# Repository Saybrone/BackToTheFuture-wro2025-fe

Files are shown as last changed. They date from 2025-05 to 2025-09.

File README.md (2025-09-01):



# Team BACK TO THE FUTURE - WRO® 2025 Future Engineers

<table border="0">
  <tr border="0">
    <td  border="0" colspan="2">
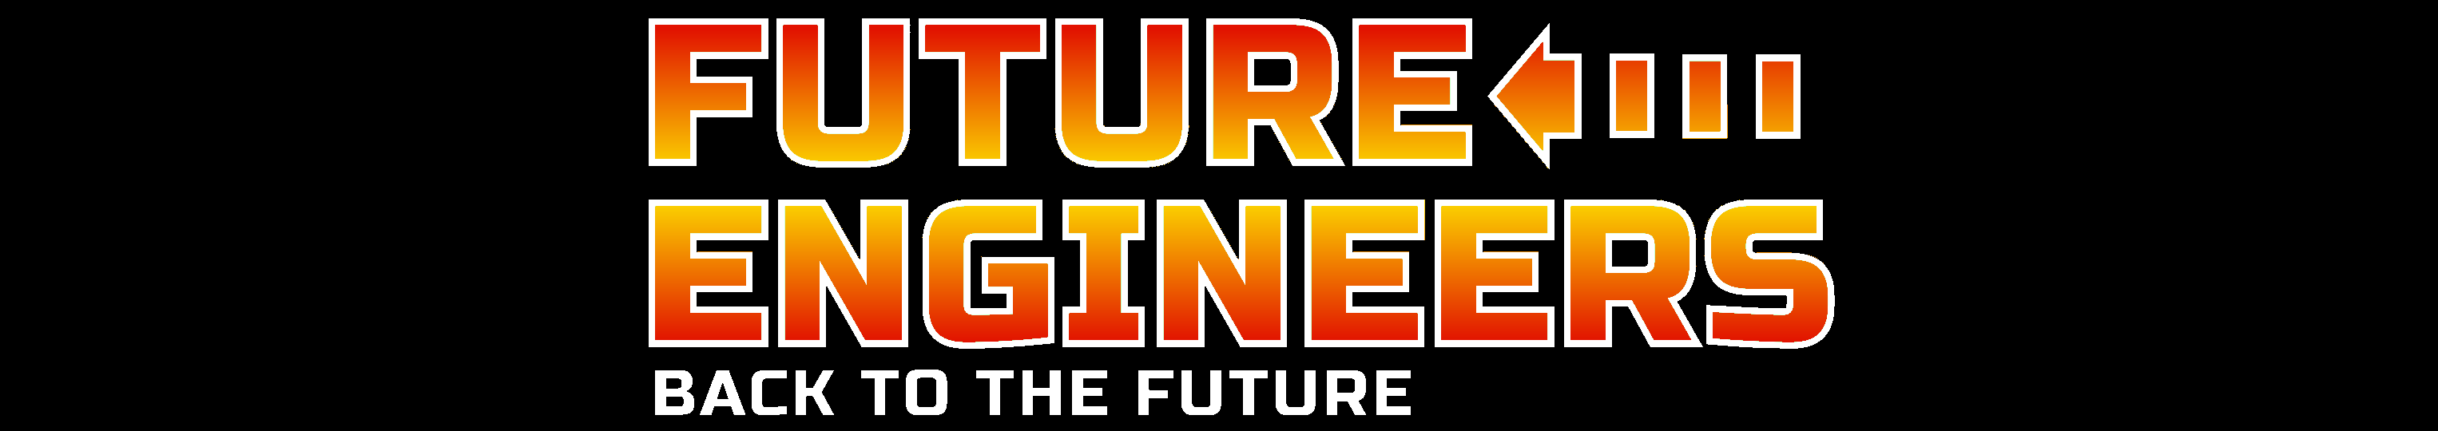
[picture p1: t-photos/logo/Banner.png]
Banner
      
    </td>
  </tr>
  <tr border="0">
    <td width="70%"  border="0">
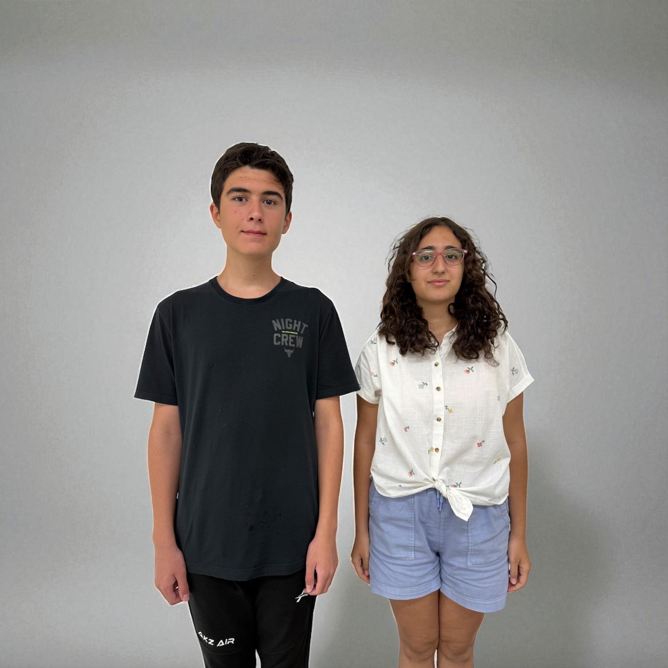
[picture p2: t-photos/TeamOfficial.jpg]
Official Photo
      
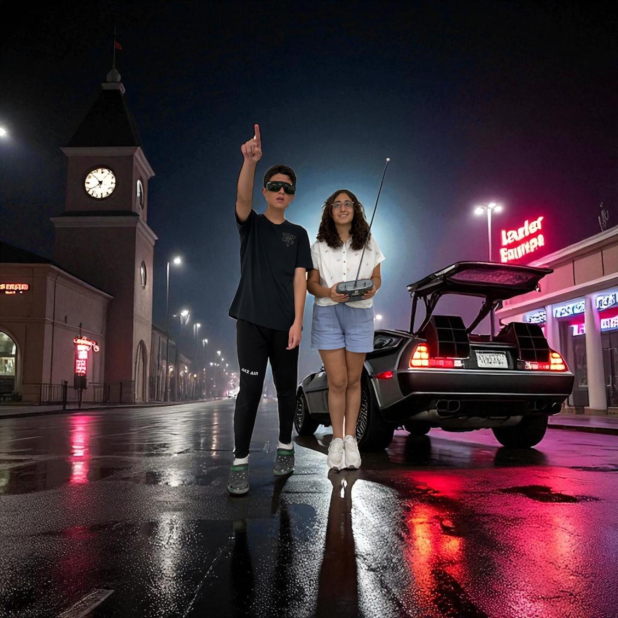
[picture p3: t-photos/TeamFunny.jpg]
Funny Photo
      
    </td>
    <td valign="top" style="padding-left: 0px;" border="0">
        This repository details team <em>Back To The Future</em>'s building and programming process in the 2025 WRO Future Engineers Competition. 
      We are team <em> Back To The Future</em>, two students who are passionate about technology and robotics. For this competition we built an autonomous vehicle. We worked after school and on weekends. Through this competition, we learned how to work as a team and solve problems related to robotics.
       </p>
        <strong>Team Members:</strong>
      <ul>
        <li>Ayça Nisa Çerçi, 16</li>
        <li>Batuhan Pekcan, 15</li>
      </ul>
      </p>
    </td>
  </tr>
</table>

  

# Table of Contents
- [Folder Contents](#folder-contents)
- [The Challenge](#the-challenge)
- [Vehicle Overview](#vehicle-overview)
  - [V-Photos](#v-photos)
  - [Hardware Components](#hardware-components)
  - [Electronic Components](#electronic-components)
  - [Mobility Management](#mobility-management)
    - [Powertrain](#powertrain)
    - [Steering](#steering)
    - [Chassis](#chassis)
- [Power and Sense Management](#power-and-sense-management)
  - [Li-ion Battery](#li-ion-battery)
  - [IMU Sensor](#imu-sensor)
  - [OpenMV Cam RT1062](#camera)
  - [EVN Alpha](#evn-alpha)
- [Software Components](#software-components)
  - [EVN Alpha Side](#evnalpha-side)
  - [OpenMV Camera Side](#openmv-side)
- [License](#license)

# Folder Contents 
* `models` is for the 3D files we used to print our parts
* `other` includes other files which can be used to understand how to prepare the vehicle for the competition. It includes documentations, datasets, hardware specifications, communication protocols,  descriptions etc.
* `schemes` contains schematic diagrams of the electromechanical components illustrating all the elements (electronic components and motors) used in the vehicle and how they connect to each other.
* `src` contains code of control software for all components which were programmed to participate in the competition
* `t-photos` contains photos of the team and logos
* `v-photos` contains 6 photos of the vehicle from various angles
* `video` contains the video.md file with the link to our YouTube channel and the respective videos

# The Challenge 

In the **[WRO 2025 Future Engineers – Self-Driving Cars](https://wro-association.org/)** category, teams are tasked with creating a robotic vehicle that can autonomously navigate a changing racetrack. Each round introduces new track layouts, requiring vehicles to adapt in real time.
The competition highlights the full engineering process:

- **Vehicle Design**: Building a functional robot with electromechanical components and advanced steering or motion systems.
- **Obstacle Management**: Applying computer vision, sensor fusion, and motion planning to make real-time decisions.
- **Project Documentation**: Maintaining an engineering journal and sharing designs in a public GitHub repository.

Teams are judged on performance, innovation, reliability, and the clarity of their engineering process, encouraging creativity, teamwork, and STEM skills.

Learn more about the challenge [here](https://wro-association.org/wp-content/uploads/WRO-2025-Future-Engineers-Self-Driving-Cars-General-Rules.pdf).

# Vehicle 
Our robot integrates LEGO components with custom 3D-printed hardware, designed to maximize stability and durability. It features a 3D-printed motor mount and camera holder, integrated with a LEGO-based chassis. For steering, we implemented a simplified Ackermann setup without linkage geometry (reckless steering), allowing the robot to turn easily while keeping the design compact. Our robot is powerized by a [GA12-N20 100RPM~6V](https://www.handsontec.com/dataspecs/GA12-N20.pdf) dc motor and controlled by an [EVNAlpha](https://evn.readthedocs.io/). It uses [OpenMV RT1062](https://openmv.io/products/openmv-cam-rt?srsltid=AfmBOorMjCmNBP1AZA_3V53JQMS-8N7Mg5ljP10ljHe4SLFoCauGWzZN) to locate obstacles, lines and walls. Steering was managed by [GeekServo 2KG Motor](https://kittenbothk-eng.readthedocs.io/en/latest/motors/2kgMotor.html). Also it uses [MPU6500 IC 6 DoF IMU Sensor](https://datasheet.octopart.com/MPU-6500-InvenSense-datasheet-138896167.pdf) to manage certain turns and hold position during movement.

## V-Photos <b class="anchor" id="v-photos"></a>
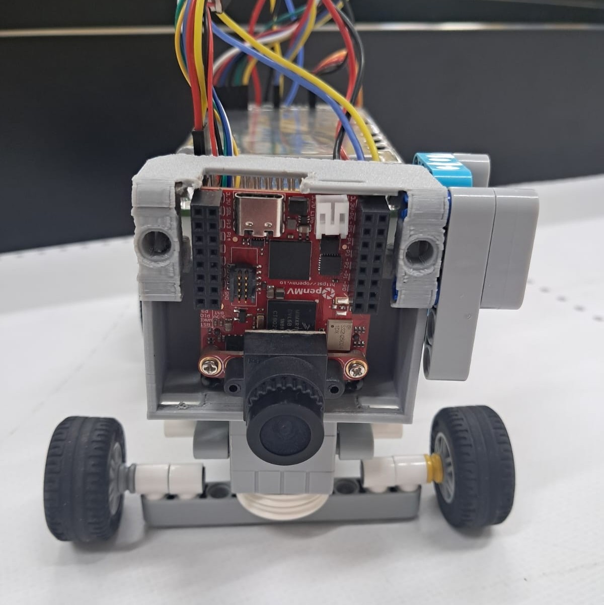
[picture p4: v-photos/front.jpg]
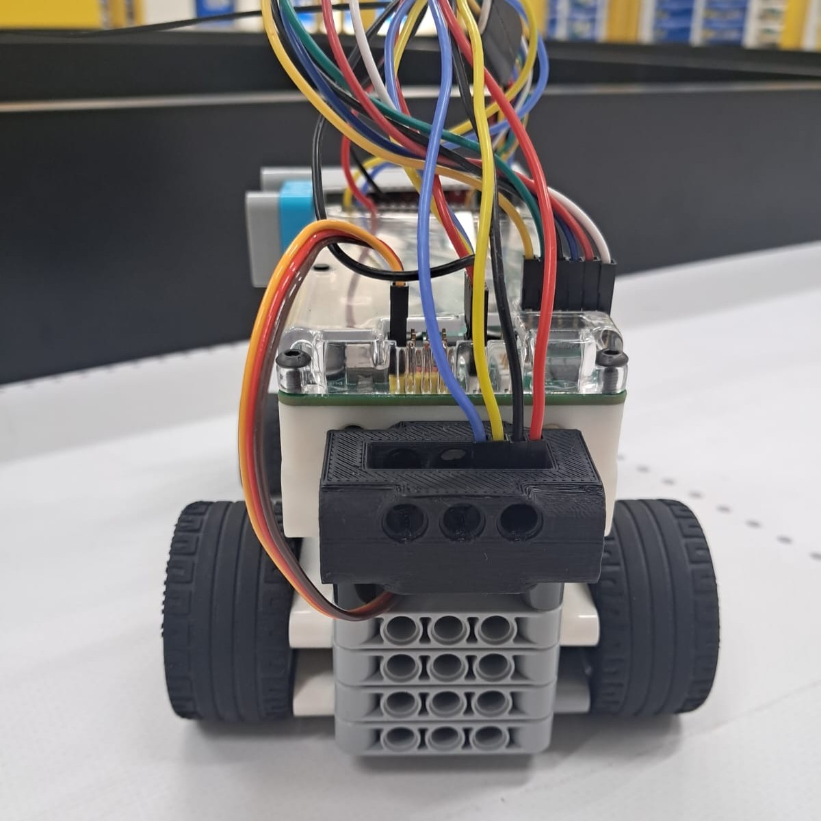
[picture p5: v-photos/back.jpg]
|  |  | 
| :--: | :--: |
| *Front* | *Back* |
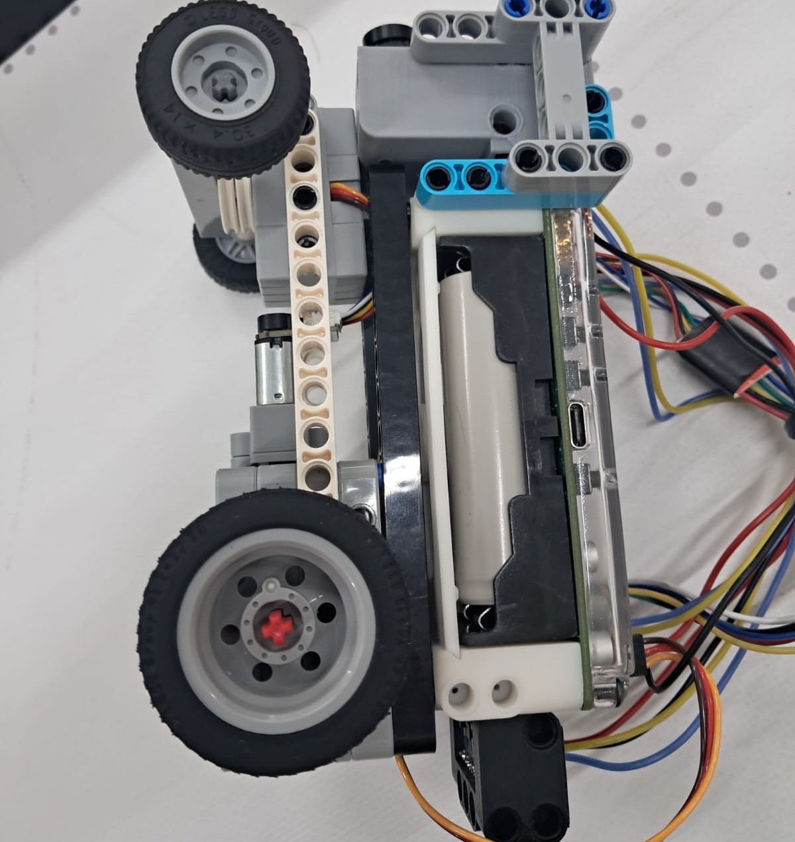
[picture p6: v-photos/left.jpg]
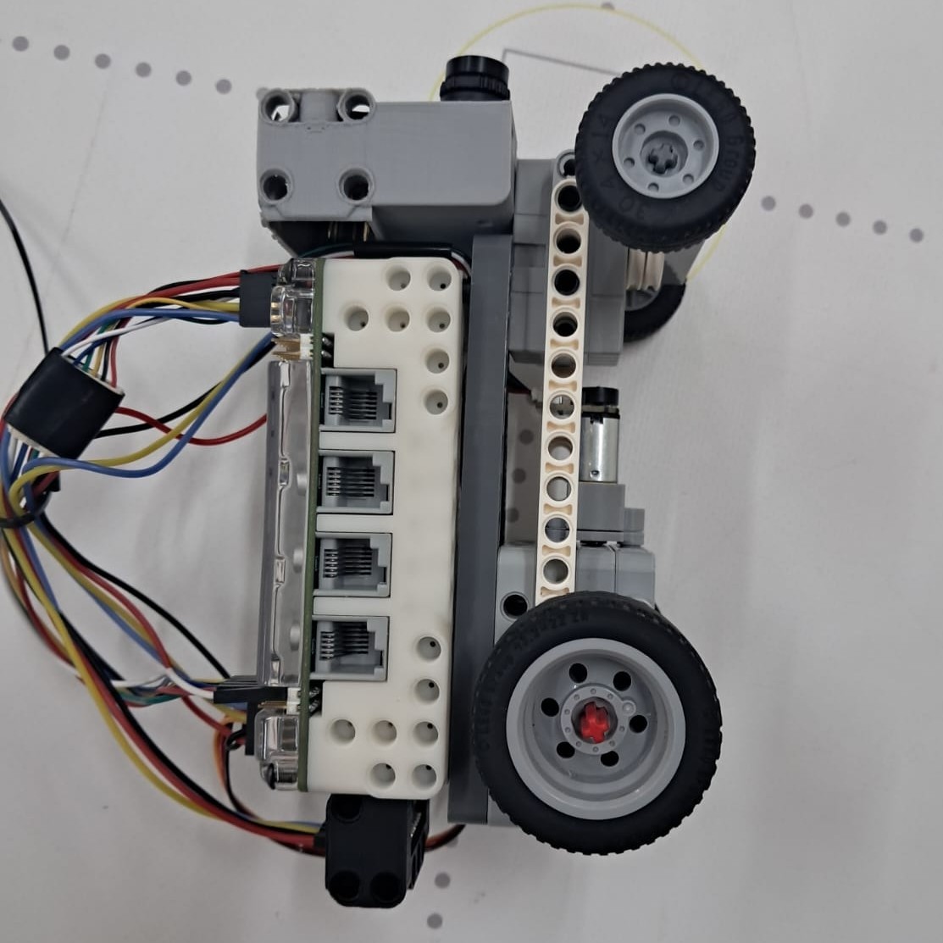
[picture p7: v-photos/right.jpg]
|  |  | 
| *Left* | *Right* |
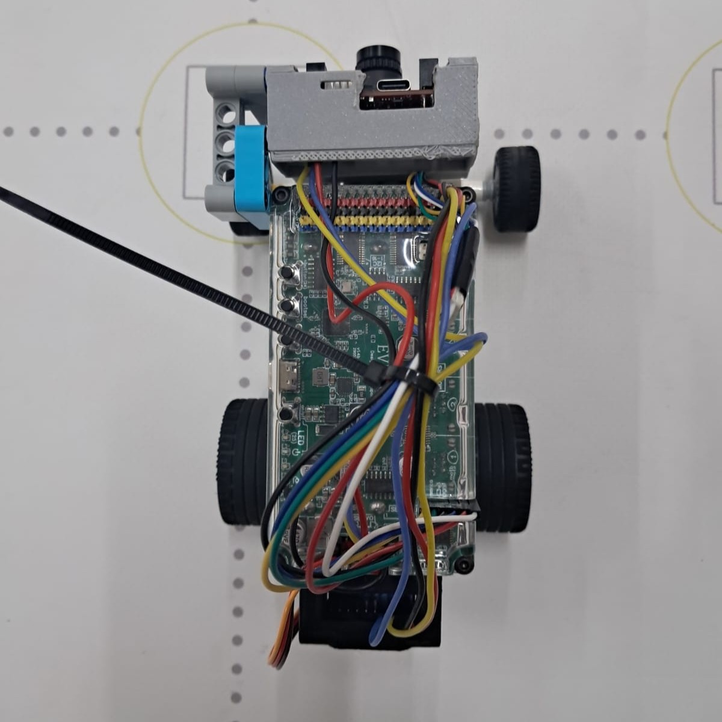
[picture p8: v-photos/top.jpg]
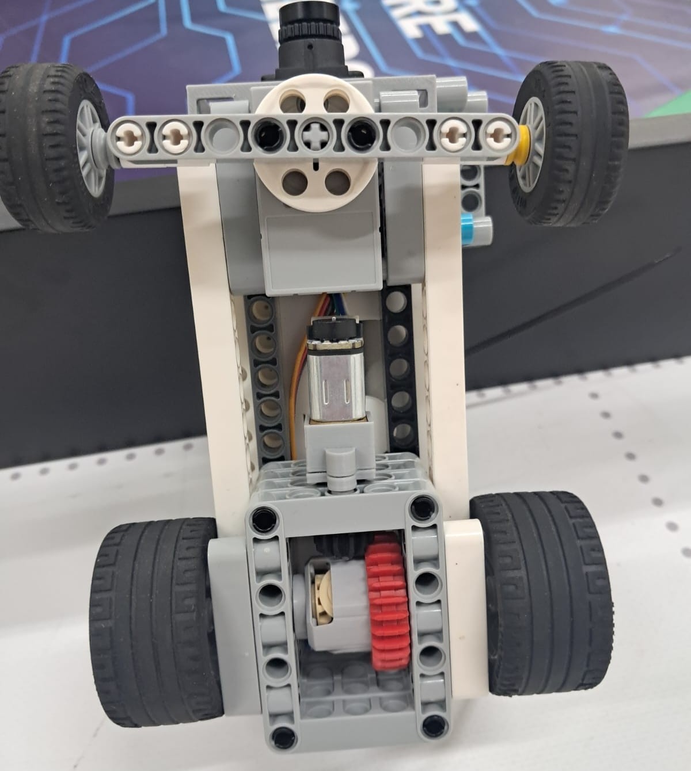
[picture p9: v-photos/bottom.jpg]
|  |  | 
| *Top* | *Bottom* |

<br>

# Hardware Components 
This section covers all the parts utilized in the vehicle, such as motors, sensors, controllers, chassis, mechanical systems, and other components.
## Electronic Components 
<table border="1" cellpadding="12" cellspacing="0">
  <thead>
    <tr>
      <th>Component</th>
      <th>Description / Link</th>
      <th>Image</th>
      <th>Price</th>
    </tr>
  </thead>
  <tbody>
    <tr>
      <td>Motor</td>
      <td><a href="https://www.aliexpress.us/item/3256805071786531.html?gatewayAdapt=glo2usa4itemAdapt">GA12 N20 Encoder DC Mini Micro Metal Gear DC Motor</td>
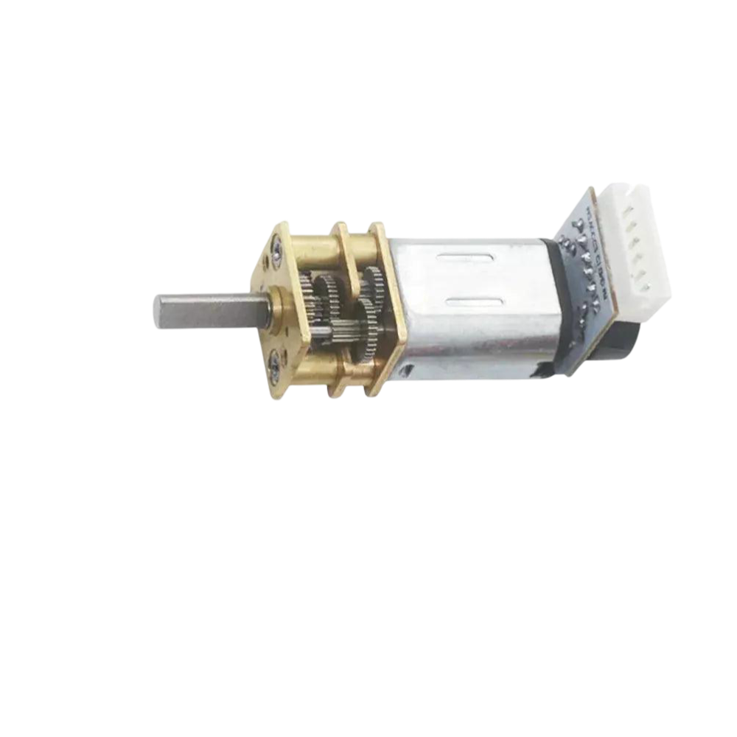
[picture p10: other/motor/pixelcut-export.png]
Motor
      <td>
      <td>$7</td>
    </tr>
    <tr>
      <td>Servo Motor</td>
      <td><a href="https://www.robotshop.com/products/geekservo-motor-2kg-compatible-w-lego">GeekServo (360 degrees)</a></td>
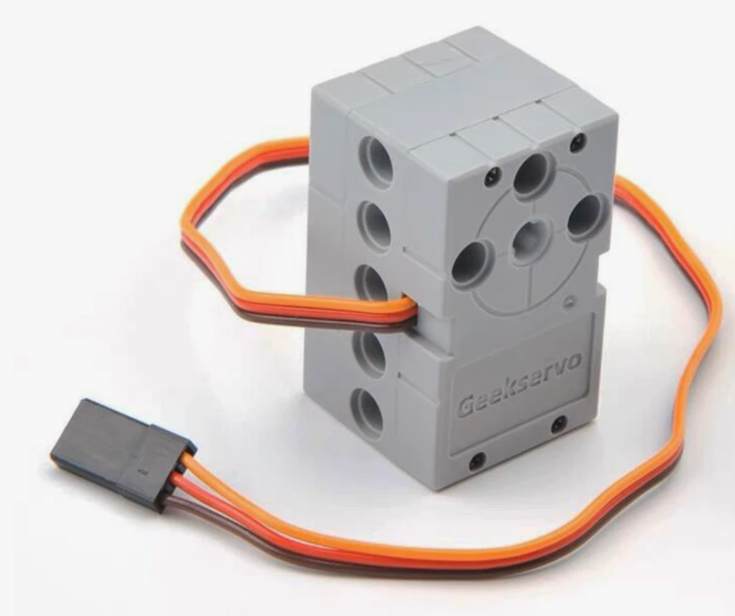
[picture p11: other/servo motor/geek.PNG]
Servo motor
      <td>
      <td>$10</td>
    </tr>
  <tr>
    <tr>
      <td>Motor Controller and Processor</td>
      <td><a href="https://coresg.tech/product/evn-alpha/">EVN Alpha</a></td>
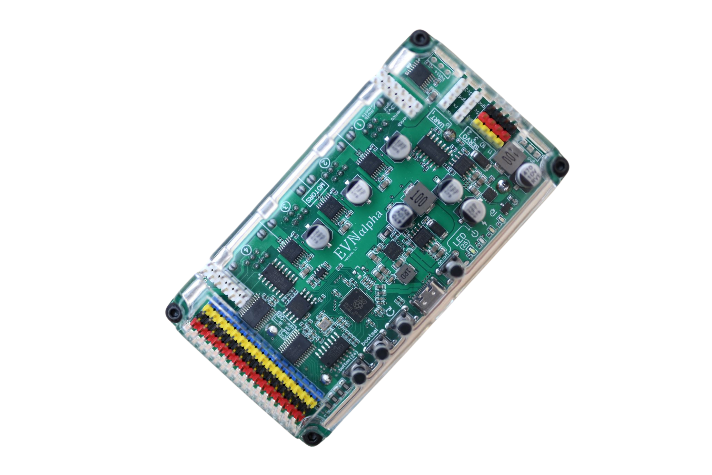
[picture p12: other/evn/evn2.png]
evn
      <td></td>
      <td>$168</td>
    </tr>
      <td>IMU</td>
      <td><a href="https://tr.aliexpress.com/item/1005006996048940.html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">MPU 6500 Gyro Sensor</td>
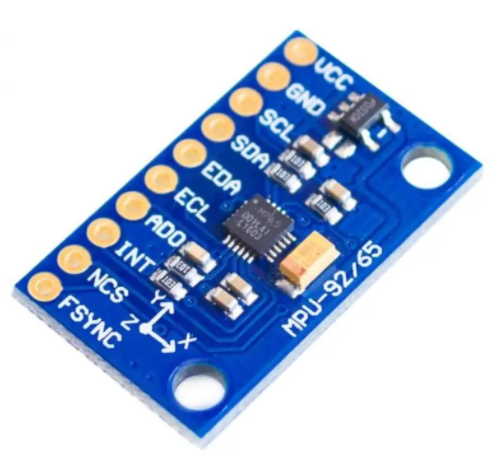
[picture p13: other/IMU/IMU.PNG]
IMU
      <td>
      <td>$1.88</td> 
    <tr>
      <td>Battery</td>
      <td><a href="https://www.pilpaketi.com/molicel-inr18650-p28a-2800-mah-35a-li-ion-pil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">Molicel 35A Li-ion battery</td>
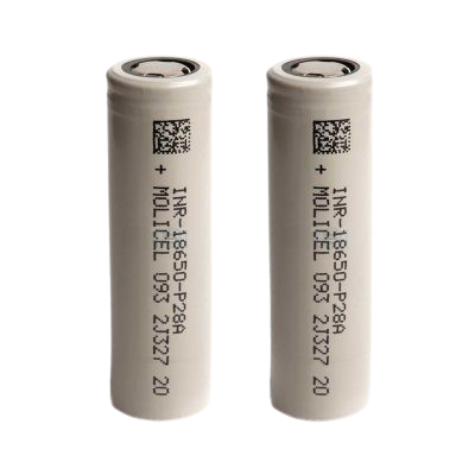
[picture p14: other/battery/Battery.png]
battery
      <td>
      <td>$10x2</td>
    </tr>
    </tr>
    <tr>
      <td>Camera</td>
      <td><a href="https://openmv.io/products/openmv-cam-rt?srsltid=AfmBOorMjCmNBP1AZA_3V53JQMS-8N7Mg5ljP10ljHe4SLFoCauGWzZN">OpenMV Cam RT1062</a></td>
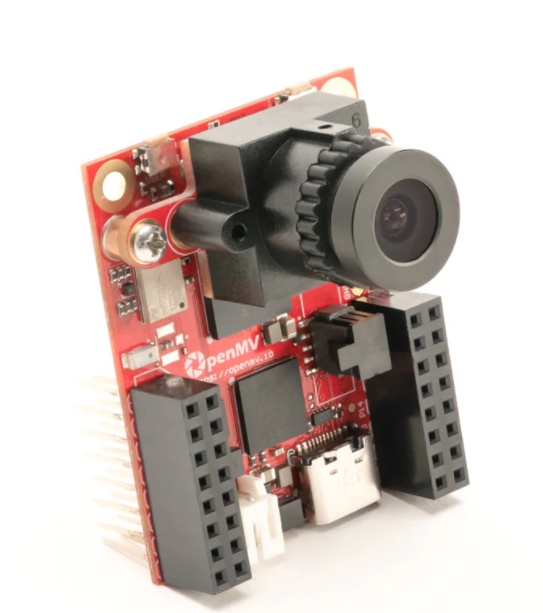
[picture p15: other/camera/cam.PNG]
Camera
      <td>
      <td>$120</td>
    </tr>
    <tr>
      <td>Lego Differential</td>
      <td><a href="https://www.amazon.com/Technical-Differential-Gear-28-Compatible-Building/dp/B0DB82HJGW">Lego Differential</td>
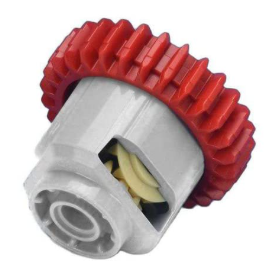
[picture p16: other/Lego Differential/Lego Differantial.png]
Differential
      <td>
      <td>$2.96</td> 
    <tr>
      <td colspan="3"><strong>Total Cost</strong></td>
      <td><strong>$329.84</strong></td>
    </tr>
  </tbody>
</table>

## Mobility Management 

Our robot’s mobility depends on the coordination of its powertrain, steering system, and chassis. Together, these components provide stability, control, and efficiency, enabling smooth and reliable movement.

### Powertrain 
The powertrain converts electrical energy into mechanical motion, driving the robot’s wheels for movement and obstacle navigation.

#### Motor
<table> <tr><td> Motor<td valign="top" style="padding-left: 15px;"> <b>Specifications:</b><br> Rated Voltage: 6~12V <br> Weight: 10g <br> Revolving Speed: 100RPM @ 6V <br> Load Speed: 80RPM <br> Rated Torque: 2 kg.cm <br> Stall Torque: 16 kg.cm <br><br> This <b>DC Mini Metal Gear Motor</b> is the one we used in our robot. Its <b>light weight</b> and <b>compact size</b> make it suitable for small robotic platforms, while the <b>high torque</b> and <b>low RPM</b> ensure powerful and controlled movement. <br><br> Thanks to its <b>excellent stall characteristics</b>, the motor provides enough force to climb slopes or overcome obstacles, which is highly beneficial for mobile robots. Additionally, the <b>durable metal gears</b> extend the lifetime of the motor, making it reliable for long-term use. <br><br> Another important advantage is that a wheel can be easily mounted on the motor’s output shaft, allowing for simple integration with the robot’s chassis. </td> </tr> </table>
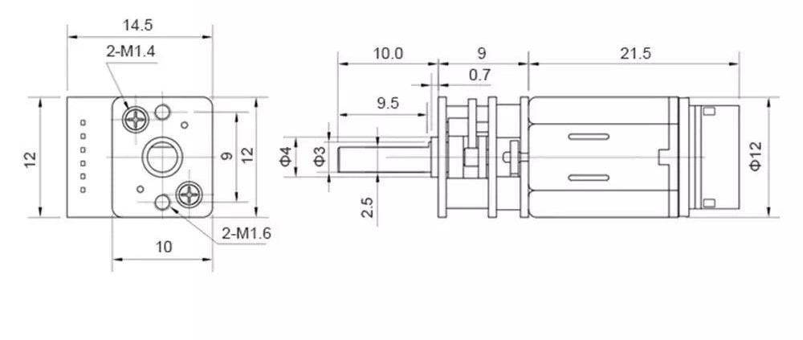
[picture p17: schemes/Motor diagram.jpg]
Diagram
<p style="margin:0;"> Below, we have included the diagram of our motor for clarity. </p> 
  
#### Differential
<table> <tr><td> Differential<td valign="top" style="padding-left: 15px;"> <b>Specifications:</b><br> Dimensions: 23 x 16 x 11 cm <br> Weight: 18 g <br><br>This Lego Differential is fully compatible with 3D shapes and Lego parts, allowing for seamless integration. It also features a 28 Teeth Differential Gear with a round axle design, providing smooth rotational movement for our robot. </td> </tr> </table>

### Steering 
Our robot uses a **reckless steering** mechanism, a simplified form of Ackermann steering where the wheels are directly turned without complex linkage geometry. This method makes the robot easier to turn and keeps the overall design compact. It is highly effective for lightweight and fast-moving prototypes where simplicity and space efficiency are key.

#### Servo Motor
<table> <tr><td>Servo motor <td valign="top" style="padding-left: 15px;"> <b>Specifications:</b><br> Operating Voltage: 3.3V~6V<br> Rated Voltage: 4.8V<br> Rotational range: 360°<br> Maximum Torque: 1.6kg±0.2kg/cm (4.8V)<br> Maximum Speed: 45rpm (3V)<br> Weight: 20g<br><br> For steering we selected the <b>GeekServo</b>. This motor is compatible with Lego Technic parts and offers a higher speed compared to 9g motors. The output shaft features a Lego Technic axle connector, making it ideal for applications that require a high-power drive. </td> </tr> </table> 
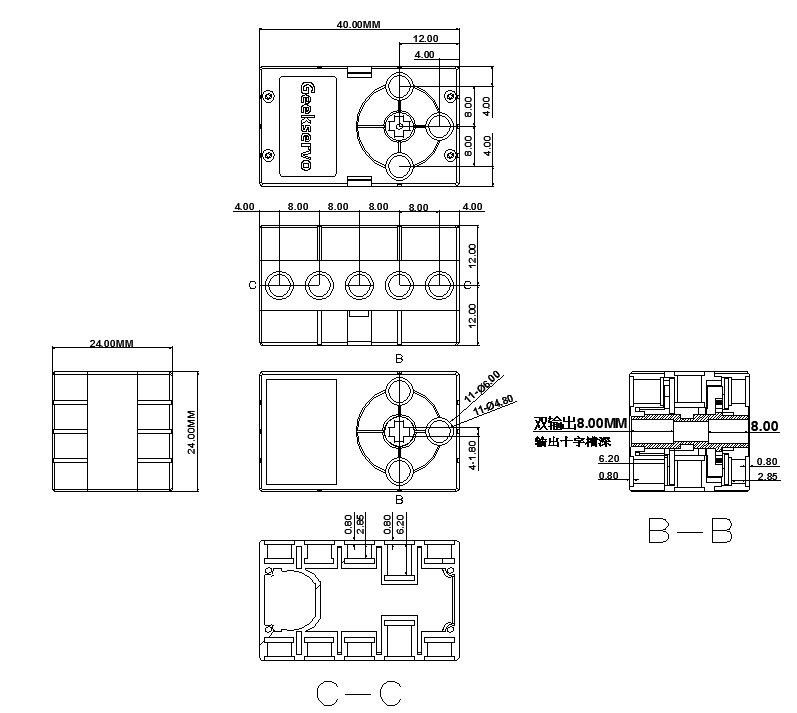
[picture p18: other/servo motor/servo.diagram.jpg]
servo diagram
<p style="margin:0;"> <p>Below, we have included the diagram of our servo motor.</p> 

[3D Model](/models/MotorMount/MotorMount.stl)

#### Motor Lego Adapter
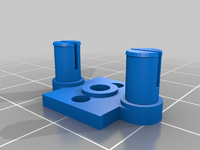
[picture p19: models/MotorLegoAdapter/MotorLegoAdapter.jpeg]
motor lego adapter
</p> 

[3D Model](/models/AxleAdapter/AxleAdapter.stl)

#### Electronic Diagram
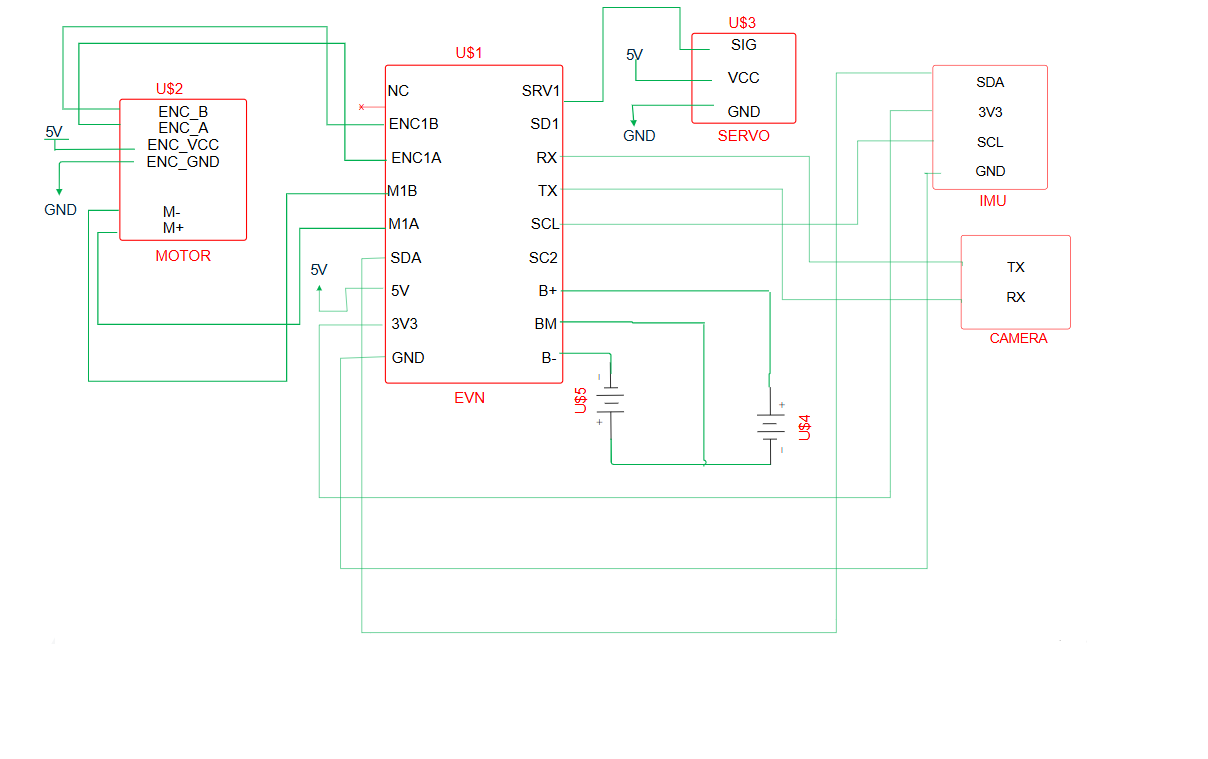
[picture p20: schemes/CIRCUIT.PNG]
schematic
</p> 
       
## Power and Sense Management 

### Li-ion Battery 
<table> <tr><td> Battery<td valign="top" style="padding-left: 15px;"> <b>Specifications:</b><br> Voltage: 3.7V <br>Capacity:2800mAh<br> Diameter: 18mm <br> Length: 65mm <br></td> </tr> </table> 

### IMU 
<table> <tr><td> IMU <b>Specifications:</b><br> Gyroscope Range: ±250, ±500, ±1000, ±2000 °/s<br>Accelerometer Range: ±2g, ±4g, ±8g, ±16g<br> Interface : I2C <br>Power Supply: 3.5V  <br> </td> </tr> </table> The MPU-6500 is a 6-axis MotionTracking sensor that combines a 3-axis gyroscope and a 3-axis accelerometer in a compact 3x3x0.9 mm package. This integration allows reliable motion detection and orientation tracking with reduced size and complexity. We selected the MPU-6500 because it provides reliable motion tracking, low power consumption, and small form factor, making it well-suited for our vehicle’s navigation and stability control.

### OpenMV Cam RT1062 
<table> <tr> <td><img src="other/camera/cam.PNG" alt = "Camera " width = "800" width:800px; height:auto; display:block; margin:0 auto;" />
 </td> <td valign="top" style="padding-left: 15px;"> <b>Specifications:</b><br> Microcontroller: ARM Cortex M7 (RT1062)<br>Frequency: 600 MHz<br> RAM: 32 MB SDRAM + 1 MB SRAM <br> Flash Memory: 16 MB program/storage flash<br>Camera Resolution: 2592 × 1944 (5 MP) <br> Frame Rate:~40 FPS on QVGA (320 × 240) <br><br> This <b>OpenMV Cam -RT1062</b> is the one we used in our robot. The OpenMV Cam is a small, low-power microcontroller board that we used in our robot to implement machine vision applications. We program the OpenMV Cam in high-level Python scripts (via the MicroPython Operating System) instead of C/C++, which makes it much easier to handle the complex outputs of machine vision algorithms and work with high-level data structures. At the same time, we retain full control over the OpenMV Cam and its I/O pins in Python. This allows our robot to locate obstacles, lines and walls, enabling intelligent, autonomous behaviors. </td> </tr> </table>

### EVN Alpha 
<table> <tr> <td><img src="other/evn/evn alpha2.jpg" alt = "evn alpha" width = "1100"  width:800px; height:auto; display:block; margin:0 auto;" />
 </td> <td valign="top" style="padding-left: 15px;"> <b>The EVN ALPHA is a compact robot controller based on the RP2040, housed in a LEGO Technic-compatible shell. It provides 26 I/O channels for controlling brushed DC motors, servos, and connecting UART or I2C peripherals. The board also integrates a 2-cell Lithium-Ion power management system, offering charging, cell balancing, and voltage regulation, making it ideal for safely powering and controlling our robot’s motors and sensors.</td> </tr> </table>
   
## Software Components 
### EVN Alpha Side 
#### 1. Setup
- Configures **servo** and **DC motor**.  
- Defines constants (angles, speeds, gyro calibration values).  
- Initializes **UART** (`Serial2`) to communicate with OpenMV.  
- Sets up **IMU (BMI088)** and calibrates **gyro bias**.  

#### 2. Gyroscope Handling
- Reads gyro Z-axis to measure angular velocity.  
- Subtracts bias → integrates over time → produces **yaw angle**.  
- Used to know robot’s heading (rotation in degrees).  
- Every movement command relies on yaw correction to stay accurate.  

#### 3. Turning Functions
- Calculate a **target yaw angle**.  
- Drive motors while comparing current yaw to target.  
- Servo steers left/right, motor power adjusts proportionally.  
- Variants:
  - `Turn()` → normal calibrated turn.  
  - `TurnWithoutCalib()` → faster, skips recalibration.  
  - `Turn_Back()` → reverse turn.  

#### 4. Forward Movement
- `Move(distance)` drives a set distance using encoders.  
- Constantly checks yaw and adjusts steering with servo.  
- Ensures straight driving.  
- `Move_w_c()` skips recalibration.  

#### 5. Camera Communication (UART)
EVN Alpha sends single-byte commands:  
- `1` → detect green box.  
- `2` → detect red box.  
- `3` → check brightness.  
- `4` → detect orange line.  
- `5` → detect blue line.  

Camera replies with formatted data: `<area,error*>` or `<1*>`.  

#### 6. Open Challenge Routine
- Calibrates IMU.  
- Uses camera to detect:  
  - **Orange line → left path**  
  - **Blue line → right path**  
  - **Brightness → walls**  
- Moves forward, checks brightness → if dark → turn 90°.  
- Repeats laps until finished.  

#### 7. Obstacle Challenge Routine
- Searches for **red/green obstacles**.  
- Uses `pass_obs()` to:  
  - Read box area + position.  
  - Adjust steering based on error.  
  - Slow down when close.  
  - Perform bypass maneuver if very close.  

Here is the EVN Alpha control code, responsible for motor control, gyroscope-based stabilization, and coordination with the OpenMV camera
```ino
#include <EVN.h>
#include <SoftwareSerial.h>
#include <math.h>

// --- Pin and Port Definitions ---
#define SERVO_DIR_PORT   1     // Steering servo control port
#define IMU_I2C_PORT     1     // IMU sensor I2C port
#define MOTOR_PORT       2     // Motor control port

// --- Motor Configuration Constants ---
#define PPR_VALUE        2200  // Motor pulses per revolution
#define MAX_RPM          77    // Maximum RPM
#define ACCEL            7700  // Acceleration
#define DECEL            7700  // Deceleration
#define MOTOR_KP         0.4   // Motor proportional gain
#define MOTOR_KD         0.0048 // Motor derivative gain

// --- Steering Servo Limits ---
const float SERVO_CENTER = 133; // Neutral steering position
const int SERVO_RIGHT  = 160;   // Maximum right turn
const int SERVO_LEFT   = 106;   // Maximum left turn

// --- Gyroscope Variables ---
float gyroBias = 0.0f;          // Bias offset for gyro
unsigned long lastTime = 0;      // Last time yaw was updated

// --- Software Serial Pins for Communication ---
const byte rxPin = 1;  // RX pin
const byte txPin = 0;  // TX pin
int timeout = 500;     // Serial communication timeout (ms)

// --- EVN Objects ---
EVNAlpha board;                     // Main EVN Alpha board
EVNServo steeringServo(SERVO_DIR_PORT);  // Steering servo object
EVNIMUSensor imu(IMU_I2C_PORT);    // IMU sensor object
EVNMotor motor(MOTOR_PORT, CUSTOM_MOTOR, DIRECT, REVERSE); // Motor object
SoftwareSerial mySerial (rxPin, txPin); // Software serial for communication

// --- Gyroscope Calibration ---
// Measure the gyro bias while vehicle is stationary
void calibrateGyroBias(uint16_t duration_ms = 200) {
  unsigned long t0 = millis();
  uint16_t n = 0;
  double sum = 0.0;

  while (millis() - t0 < duration_ms) {
    float gz = imu.readGyroZ(); // Read angular velocity (deg/s)
    sum += gz;
    n++;
    delay(4); // Sample at ~250 Hz
  }

  if (n > 0) gyroBias = (float)(sum / n); // Average bias
}

// --- Yaw Angle Update ---
// Integrates gyro data to calculate yaw (rotation around Z-axis)
float yaw = 0.0f;
float updateYaw() {
  unsigned long now = millis();
  float dt = (now - lastTime) / 1000.0f; // Time delta in seconds
  lastTime = now;
  
  float gz = imu.readGyroZ(); // Read Z-axis gyro
  gz -= gyroBias;             // Apply bias correction
  yaw += gz * dt;             // Integrate angular velocity
  return yaw;
}

// ======================= TURNING FUNCTIONS =======================

// --- Turn the robot a specific angle with gyro calibration ---
// Turn_Degree: Target turn in degrees (+right, -left)
// kp: Proportional gain for speed control
// turn_start_yaw: Reference yaw angle before starting
// min_speed, max_speed: Speed limits during turn
// servo_right/servo_left: Max servo angles for turning
// servo_min/servo_max: Servo range limits
void Turn(float Turn_Degree, float kp = 6.66, float turn_start_yaw = 0.0,
          float min_speed = 40, float max_speed = 400, float Near_Degree = 20.0f,
          int servo_right = 160, int servo_left = 115, int servo_min = 50, int servo_max = 210) {

  delay(1000);                 // Short delay before turn
  calibrateGyroBias(200);      // Calibrate gyro for accurate turn
  float Turn_Degree_first = Turn_Degree - updateYaw(); // Remaining turn angle
  int turnAngle = (Turn_Degree_first >= 0.0f) ? servo_right : servo_left; // Decide turn direction
  float error = 0;

  // Set steering servo to initial turn angle
  steeringServo.write(constrain(turnAngle, servo_min, servo_max));
  
  float diff = updateYaw() - turn_start_yaw; // Current yaw relative to start
  // Continue turning until target angle reached
  while((Turn_Degree_first >= 0.0f) ? (Turn_Degree - diff > 0.1) : (Turn_Degree - diff < 0.1)){
    diff = updateYaw() - turn_start_yaw;
    error = Turn_Degree - diff;       // Remaining angle error
    float remaining = fabsf(Turn_Degree) - fabsf(diff); // Not used here
    int spd = fabsf(error * kp);       // Speed proportional to error
    Serial.println(updateYaw());       // Print current yaw for debugging

    // Limit speed to min/max
    if (spd > max_speed) spd = max_speed;
    if (spd < min_speed) spd = min_speed;

    motor.runSpeed(spd);               // Move motor during turn
  }

  motor.stop(); // Stop after reaching target
  steeringServo.write(constrain(SERVO_CENTER, servo_min, servo_max)); // Reset steering
}

// --- Turn the robot without gyro calibration ---
// Useful when calibration was already done
void TurnWithoutCalib(float Turn_Degree, float kp = 6.66, float turn_start_yaw = 0.0,
                      float min_speed = 40, float max_speed = 400, float Near_Degree = 20.0f,
                      int servo_right = 160, int servo_left = 115, int servo_min = 50, int servo_max = 210) {

  float Turn_Degree_first = Turn_Degree - updateYaw(); // Remaining turn
  Serial.println("-----");
  Serial.println(Turn_Degree_first);

  int turnAngle = (Turn_Degree_first >= 0.0f) ? servo_right : servo_left;
  float error = 0;

  steeringServo.write(constrain(turnAngle, servo_min, servo_max)); // Initial turn

  float diff = updateYaw() - turn_start_yaw;
  // Loop until target turn reached
  while((Turn_Degree_first >= 0.0f) ? (Turn_Degree - diff > 0.1) : (Turn_Degree - diff < 0.1)){
    diff = updateYaw() - turn_start_yaw;
    error = Turn_Degree - diff;
    float remaining = fabsf(Turn_Degree) - fabsf(diff);
    int spd = fabsf(error * kp);

    if (spd > max_speed) spd = max_speed;
    if (spd < min_speed) spd = min_speed;

    motor.runSpeed(spd);
    Serial.println(error); // Debug: current error
  }

  motor.stop();
  steeringServo.write(constrain(SERVO_CENTER, servo_min, servo_max));
  Serial.println(updateYaw()); // Debug: final yaw
}

// --- Turn backward with gyro calibration ---
// Same logic as Turn(), but motor moves in reverse (-spd)
void Turn_Back(float Turn_Degree, float kp = 6.66, float turn_start_yaw = 0.0,
               float min_speed = 40, float max_speed = 400, float Near_Degree = 20.0f,
               int servo_right = 160, int servo_left = 115, int servo_min = 50, int servo_max = 210) {

  delay(1000);
  calibrateGyroBias(200);
  float Turn_Degree_first = Turn_Degree - updateYaw();
  int turnAngle = (Turn_Degree_first < 0.0f) ? servo_right : servo_left;
  float error = 0;

  steeringServo.write(constrain(turnAngle, servo_min, servo_max));

  float diff = updateYaw() - turn_start_yaw;
  while((Turn_Degree_first >= 0.0f) ? (Turn_Degree - diff > 0.1) : (Turn_Degree - diff < 0.1)){
    diff = updateYaw() - turn_start_yaw;
    error = Turn_Degree - diff;
    int spd = fabsf(error * kp);

    if (spd > max_speed) spd = max_speed;
    if (spd < min_speed) spd = min_speed;

    motor.runSpeed(-spd); // Reverse motor
  }

  motor.stop();
  steeringServo.write(constrain(SERVO_CENTER, servo_min, servo_max));
  Serial.println(updateYaw());
}

// --- Turn backward without calibration ---
// Similar to Turn_Back but skips gyro calibration
void Turn_Back_WithoutCalib(float Turn_Degree, float kp = 6.66, float turn_start_yaw = 0.0,
                            float min_speed = 40, float max_speed = 400, float Near_Degree = 20.0f,
                            int servo_right = 160, int servo_left = 115, int servo_min = 50, int servo_max = 210) {

  float error = 0;
  float Turn_Degree_first = Turn_Degree - updateYaw();
  int turnAngle = (Turn_Degree_first < 0.0f) ? servo_right : servo_left;
  steeringServo.write(constrain(turnAngle, servo_min, servo_max));

  float diff = updateYaw() - turn_start_yaw;
  while((Turn_Degree_first >= 0.0f) ? (Turn_Degree - diff > 0.1) : (Turn_Degree - diff < 0.1)){
    diff = updateYaw() - turn_start_yaw;
    error = Turn_Degree - diff;
    int spd = fabsf(error * kp);

    if (spd > max_speed) spd = max_speed;
    if (spd < min_speed) spd = min_speed;

    motor.runSpeed(-spd);
  }

  motor.stop();
  steeringServo.write(constrain(SERVO_CENTER, servo_min, servo_max));
  Serial.println(updateYaw());
}

// ======================= MOVEMENT FUNCTIONS =======================

// --- Move robot forward a specific distance ---
// distance_mm: Target distance in millimeters
// speed: Motor speed
void Move(float distance_mm, float speed = 600) {
  steeringServo.write(constrain(SERVO_CENTER, 50, 210)); // Keep straight
  delay(1000);
  calibrateGyroBias(200);

  long start_pos = motor.getPosition(); // Get initial motor position
  float diameter = 43.2; // Wheel diameter
  float distance_degree = 360 * distance_mm / (3.1415 * diameter); // Convert mm to degrees
  long pos = motor.getPosition() - start_pos;
  float start_yaw = updateYaw();

  while (llabs(pos) < distance_degree) { // Loop until distance reached
    float error = updateYaw() - start_yaw; // Yaw deviation
    steeringServo.write(constrain(SERVO_CENTER - error, 50, 210)); // Correct steering
    pos = motor.getPosition() - start_pos;
    motor.runSpeed(speed);
    Serial.println(motor.getPosition()); // Debug: current motor position
    Serial.println(llabs(pos));
  }

  motor.stop();
}

// --- Move forward without gyro recalibration ---
// Useful when moving after already calibrated
void Move_w_c(float distance_mm, float speed = 600) {
  steeringServo.write(constrain(SERVO_CENTER, 50, 210));
  long start_pos = motor.getPosition();
  float diameter = 43.2;
  float distance_degree = 360 * distance_mm / (3.1415 * diameter);
  long pos = motor.getPosition() - start_pos;
  float start_yaw = updateYaw();

  while (llabs(pos) < distance_degree) {
    float error = updateYaw() - start_yaw;
    steeringServo.write(constrain(SERVO_CENTER - error, 50, 210));
    pos = motor.getPosition() - start_pos;
    motor.runSpeed(speed);
    Serial.println(motor.getPosition());
    Serial.println(llabs(pos));
  }

  motor.stop();
}

// ======================= SETUP FUNCTIONS =======================

// Initialize motor and servo (simple setup)
void setup1() {
  motor.begin();           // Start motor controller
  steeringServo.begin();   // Start servo controller
}

// Standard setup function
void setup() {
  board.begin();            // Initialize EVNAlpha board
  Serial.begin(9600);       // Start serial communication for debugging
  imu.begin();              // Initialize IMU (gyro + accelerometer)
  imu.setGyroRange(IMU_GYRO_DPS_1000); // Set gyro range to ±1000 deg/sec

  // Motor configuration
  motor.setPPR(PPR_VALUE); // Encoder pulses per revolution
  motor.setMaxRPM(MAX_RPM); // Max motor speed
  motor.setAccel(ACCEL);    // Acceleration
  motor.setDecel(DECEL);    // Deceleration
  motor.setKp(MOTOR_KP);    // Proportional gain for speed control
  motor.setKd(MOTOR_KD);    // Derivative gain for speed control
  motor.resetPosition();     // Reset encoder position

  // Center the steering servo
  steeringServo.write(SERVO_CENTER, 50, 210);

  // Initialize SoftwareSerial pins
  pinMode(rxPin, INPUT);
  pinMode(txPin, OUTPUT);
  mySerial.begin(9600);

  lastTime = millis();       // Store initial time for yaw calculations
}

// ======================= SENSOR DECISION FUNCTION =======================

// Determines robot direction based on line or brightness sensors
// Returns:
// 1 = Orange line detected
// 2 = Blue line detected
// 0 = No line, brightness determines direction
int find_direction() {
  Serial.println("<");            // Debug: start reading
  String orange = requestOrangeLine(); 
  String blue = requestBlueLine();
  String bright = requestMiddleBrightness();
  float bright1 = bright.toFloat(); // Convert brightness to float
  Serial.println(">");            // Debug: end reading

  if (orange == "True") {         // Orange line detected
    return 1;
  } else if (blue == "True") {    // Blue line detected
    return 2;
  } else {                        // No line detected
    if (bright1 < 12) {           // Dark area, assume orange direction
      return 1;
    } else {                       // Bright area, go straight/no line
      return 0;
    }
  }
}

// ======================= OPEN CHALLENGE FUNCTION =======================

// Navigate open space using sensors
void open_challenge() {
  calibrateGyroBias(200);       // Calibrate gyro for accurate movement
  timeout = 2000;               // Increase serial timeout for sensor reading
  find_direction();              // Initial check for direction
  timeout = 500;                // Reset timeout

  long start_pos = motor.getPosition(); // Save initial motor position
  float kp = 1;
  long pos = motor.getPosition() - start_pos;
  float error = 0;
  float start_yaw = updateYaw();       // Reference yaw angle
  bool found_line_or_brightness = false;
  int a;
  Serial.println("S");                 // Debug: start signal
  // Move forward until line or brightness is detected
  while(true) {
    board.ledWrite(true);               // Turn on board LED
    Serial.println(motor.getPosition());
    
    error = updateYaw() - start_yaw;   // Compute yaw deviation
    steeringServo.write(constrain(SERVO_CENTER - error, 50, 210)); // Correct steering
    
    pos = motor.getPosition() - start_pos;
    Serial.println(llabs(pos));         // Debug: distance traveled
    motor.runSpeed(300);               // Move forward slowly
    a = find_direction();               // Check sensors
    if (a != 0) {
      found_line_or_brightness = true; // Line or brightness detected
    }
    if (found_line_or_brightness) break;
  }

  Serial.println(a);                     // Debug: which line detected
  steeringServo.write(SERVO_CENTER, 50, 210); // Center steering

  // If orange line detected, follow path logic
  if (a == 1) {
    int lap = 1;
    while(true) {
      Serial.println(motor.getPosition());
      error = updateYaw() - start_yaw;
      steeringServo.write(constrain(SERVO_CENTER - error, 50, 210));
      pos = motor.getPosition() - start_pos;
      Serial.println(llabs(pos));
      motor.runSpeed(700);              // Move faster

      String bright = requestMiddleBrightness();
      float bright1 = bright.toFloat();
      if (bright1 < 12) {               // Dark patch detected
        motor.stop();
        Turn(90 * lap);                 // Turn 90 degrees per lap
        start_yaw = updateYaw();        
        lap += 1;
      }
      if (lap == 13) break;             // Stop after 12 laps
    }
    Move(400);                           // Move forward 400 mm
    motor.stop();
  }
  // If blue line detected, similar logic but turn left (-90 deg)
  if (a == 2) {
    motor.stop();
    int lap = 1;
    while(true) {
      int x = millis();
      Serial.println(motor.getPosition());
      error = updateYaw() - start_yaw;
      steeringServo.write(constrain(SERVO_CENTER - error, 50, 210));
      pos = motor.getPosition() - start_pos;
      Serial.println(llabs(pos));
      motor.runSpeed(700);
      String bright = requestMiddleBrightness();
      float bright1 = bright.toInt();
      Serial.println(bright1);
      if (bright1 < 12) {                // Dark patch detected
        motor.stop();
        Turn(-90 * lap);                 // Turn left
        start_yaw = updateYaw();
        lap += 1;
      }
      int y = millis();
      Serial.println((x - y));          // Debug: loop timing
      if (lap == 13) break;             // Stop after 12 laps
    }
    Move(400);                           // Move forward 400 mm
    motor.stop();
  }
  motor.stop();                           // Stop at end of challenge
}

// ======================= TURN IN BLACK =======================

// This function moves the robot forward until it detects a black line (very low brightness).
// Once detected, it stops and performs a backward turn based on 'direction'.
void Turn_In_Black(int direction) {
  calibrateGyroBias(200); // Calibrate gyro for accurate steering
  timeout = 500;           // Set timeout for sensor readings

  float kp = 0.5;          // Steering correction factor
  float error = 0;
  float startYaw = updateYaw(); // Save initial yaw angle

  while (true) {
    error = updateYaw() - startYaw;                      // Calculate yaw deviation
    steeringServo.write(constrain(SERVO_CENTER - error, 50, 210)); // Correct steering

    Serial.print("Yaw error: "); Serial.println(error);

    motor.runSpeed(700);                                  // Move forward

    String brightnessStr = requestMiddleBrightness();     // Read middle brightness sensor
    float brightness = brightnessStr.toInt();
    Serial.print("Brightness: "); Serial.println(brightness);

    if (brightness < 5) { // Black line detected
      motor.stop();
      Turn_Back(90 * direction); // Turn backward in the specified direction
      startYaw = updateYaw();
      break;
    }
  }
}

// ======================= PARSE SENSOR DATA =======================

// Parses area and error values from a string like "[area,error]"
// Returns the number of items parsed
int parseAreaErrorList(String data, int areas[], int errors[], int maxSize) {
  int count = 0;
  int startIndex = 0;

  while (count < maxSize) {
    int open = data.indexOf('[', startIndex); if (open == -1) break;
    int comma = data.indexOf(',', open);     if (comma == -1) break;
    int close = data.indexOf(']', comma);    if (close == -1) break;

    // Extract area and error as integers
    areas[count] = data.substring(open + 1, comma).toInt();
    errors[count] = data.substring(comma + 1, close).toInt();
    count++;

    startIndex = close + 1;
  }
  return count;
}

// ======================= FIND FIRST OBSTACLE =======================

// Checks if any red or green box is detected; if none, uses Turn_In_Black
void find_first_obstacle(bool goLeft) {
  String redBox = requestRedBox();
  String greenBox = requestGreenBox();
  if (redBox == "" && greenBox == "") {
    if (goLeft) {
      Turn_In_Black(-1);
    } else {
      Turn_In_Black(1);
    }
  }
}

// ======================= PASS OBSTACLES =======================

// Handles passing obstacles based on sensor input (red/green boxes)
void pass_obs(int directon_degree){
  int startTime = millis();
  
  // Get sensor data
  String redBox = requestRedBox();
  String greenBox = requestGreenBox();
  
  // Arrays for storing parsed area/error values
  int areas_red[10], errors_red[10];
  int areas_green[10], errors_green[10];
  int areas_box[10], errors_box[10];
  
  int count = parseAreaErrorList(redBox, areas_red, errors_red, 10);
  int count_green = parseAreaErrorList(greenBox, areas_green, errors_green, 10); 
  int count_box;
  bool redtrue_greenfalse; 
  int k = 0;

  // Decide which box type to follow based on detected areas
  if ((count > 0) && (count_green == 0)) redtrue_greenfalse = true;
  else if ((count == 0) && (count_green > 0)) redtrue_greenfalse = false;
  else if ((count > 0) && (count_green > 0)) redtrue_greenfalse = (areas_red[0] > areas_green[0]);

  while(true){
    updateYaw(); // Update yaw for steering

    // Choose which box data to follow
    String Box = redtrue_greenfalse ? requestRedBox() : requestGreenBox();
    count_box = parseAreaErrorList(Box, areas_box, errors_box, 10);

    // Swap largest area to front if more than 1 box
    if (count_box > 1) {
      if (areas_box[0] < areas_box[1]) {
        swap(areas_box[0], areas_box[1]);
        swap(errors_box[0], errors_box[1]);
      }
    }

    int error_now = errors_box[0];

    // Adjust motor speed based on obstacle size
    if (areas_box[0] > 5000) motor.runSpeed(100);
    else motor.runSpeed(200);

    // Adjust steering based on box error
    int move1 = SERVO_CENTER + (error_now * 0.2);
    move1 = constrain(move1, SERVO_LEFT, SERVO_RIGHT);
    steeringServo.write(constrain(move1, 50, 210));

    // If obstacle is large enough, execute avoidance maneuver
    if (areas_box[0] > 7000 && count > 0) {
      motor.stop();
      k++;

      if (redtrue_greenfalse) {
        Turn_Back_WithoutCalib(directon_degree + 50);
        TurnWithoutCalib(directon_degree + 70);
        Move_w_c(50);
        TurnWithoutCalib(directon_degree - 10);
      } else {
        Turn_Back_WithoutCalib(directon_degree - 50);
        TurnWithoutCalib(directon_degree - 70);
        Move_w_c(50);
        TurnWithoutCalib(directon_degree + 10);  
      }

      // Update box data after maneuver
      redBox = requestRedBox();
      greenBox = requestGreenBox();
      count = parseAreaErrorList(redBox, areas_red, errors_red, 10);
      count_green = parseAreaErrorList(greenBox, areas_green, errors_green, 10);  

      // Decide which box to follow next
      if (count > 0 && count_green == 0) redtrue_greenfalse = true;
      else if (count == 0 && count_green > 0) redtrue_greenfalse = false;
      else if (count > 0 && count_green > 0) redtrue_greenfalse = (areas_red[0] > areas_green[0]);
      else break;

      if (k == 2) break; // Stop after 2 maneuvers
    }
  }

  // Final turn to align after passing obstacle
  Turn(directon_degree);
  if (directon_degree <= 0) Turn_In_Black((directon_degree / 90) - 1);
  else Turn_In_Black((directon_degree / 90) + 1);
}

// ======================= OBSTACLE CHALLENGE =======================

// Main routine to navigate the obstacle course
void obstacle_challenge() {
  calibrateGyroBias(200);      // Calibrate gyro for accurate steering

  // Series of corrective turns to align robot at the start
  Turn(-10, 15);
  Turn_Back_WithoutCalib(-20, 15, 0.0, 80);
  TurnWithoutCalib(-30, 15, 0.0, 80);
  Turn_Back_WithoutCalib(-50, 15, 0.0, 80);
  TurnWithoutCalib(-70, 15, 0.0, 80);
  Turn_Back_WithoutCalib(-90, 15, 0.0, 80);

  Move(40);                    // Move forward 40 mm
  Turn(0);                      // Align straight
  find_first_obstacle(true);    // Search for first obstacle, default go left

  // Navigate multiple obstacles
  for (int i = 1; i < 12; i++) {
    pass_obs(-90 * i);          // Pass obstacles using calculated turn angles
  }

  // Print final yaw angle for debugging
  Serial.print("Final Yaw: ");
  Serial.println(updateYaw());
}

// ======================= LOOP =======================

// Main loop; executes the challenge once and halts
void loop() { 
  obstacle_challenge();
  delay(999999);                // Prevent repeating (simulate "end of challenge")
}

// ======================= SERIAL COMMUNICATION =======================

// Global buffer for storing serial messages
char m[100];
char c;
int i;

// Reads messages from serial port, delimited by '<' (start) and '*' (end)
String readMessage() {
  bool started = false;
  int i = 0;
  unsigned long startTime = millis();

  while (true) {
    updateYaw();                 // Update yaw for real-time steering correction

    if (mySerial.available() > 0) {
      char c = mySerial.read();

      if (c == '<') {            // Start of message
        started = true;
        i = 0;
      } 
      else if (c == '*' && started) { // End of message
        m[i] = '\0';
        String result = String(m);
        Serial.println(result); 
        Serial.println(millis() - startTime);
        return result;
      } 
      else if (started && i < sizeof(m) - 1) { // Store characters
        m[i++] = c;
      }
    }

    if (millis() - startTime > timeout) { // Timeout
      return "";
    }
  }
}

// Request functions for specific sensor data

// Request green box detection data
String requestGreenBox() {
  mySerial.write('1');          // Send request code
  return readMessage();          // Read response
}

// Request red box detection data
String requestRedBox() {
  mySerial.write('2');
  return readMessage();
}

// Request middle brightness sensor value
String requestMiddleBrightness() {
  mySerial.write('3');
  String msg = readMessage();
  if (msg == "") msg = "100";   // Default if no message
  return msg;
}

// Request detection of orange line
String requestOrangeLine() {
  mySerial.write('4');
  String msg = readMessage();
  if (msg == "") msg = "False"; // Default if no message
  return msg;
}

// Request detection of blue line
String requestBlueLine() {
  mySerial.write('5');
  String msg = readMessage();
  if (msg == "") msg = "False"; // Default if no message
  return msg;
}
```
### OpenMV Camera Side 

#### 1. Color Detection
- **Orange / Blue line**:  
  - Detects blobs in bottom ROI.  
  - Returns `True` if blob is large enough.  
- **Red / Green box**:  
  - Detects rectangular blobs.  
  - Filters by size and shape.  
  - Returns `[area, error]` for EVN Alpha.  

#### 2. Brightness Detection
- Reads a central ROI.  
- Computes average brightness.  
- Low brightness → wall detected.  

#### 3. UART Control
- Waits for EVN Alpha command.  
- Runs appropriate detection function.  
- Sends results back wrapped in `<...*>`.  

Example:  
- EVN Alpha sends `1`.  
- Camera detects green box.  
- Camera replies: `<500,20*>` (area=500, error=20px right).
```py
import sensor, time
from machine import UART

sensor.reset()
sensor.set_pixformat(sensor.RGB565)
sensor.set_framesize(sensor.QVGA)
sensor.set_auto_gain(False)
sensor.set_auto_whitebal(False)
#---Flips sensor data because it is upside down---
sensor.set_vflip(True)
sensor.set_hmirror(True)

sensor.skip_frames(time=2000)
uart1 = UART(1, baudrate=9600) #Starts Uart Communication in pin "P4" and "P5"

clock = time.clock()
img_width = sensor.width()
img_height = sensor.height()

#---Finds brightness in middle to detect wall---
def Find_MiddleBrightness(img):
    #---Defining a rectangle roi for middle---
    rect_x = int(img_width * 0.3)
    rect_y = int(img_height * 0.35)
    rect_w = int(img_width * 0.4)
    rect_h = int(img_height * 0.3)
    middle_roi = (rect_x, rect_y, rect_w, rect_h)

    #---Gets the average brightness of the pixels in roi---
    stats = img.get_statistics(roi=middle_roi)
    brightness = stats.mean()
    return brightness

#---Detects Orange Line to determine the direction---
def Find_Orange_Line(img):
    orange_threshold = (40, 51, -115, 68, 16, 29) #Color threshold used for orange

    #---Defines a rectangle roi for the floor---
    rect_x = int(0)
    rect_y = int(img_height * 0.3)
    rect_w = int(img_width)
    rect_h = int(img_height)
    lines_roi = (rect_x, rect_y, rect_w, rect_h)

    #---Finds similar colored pixel blocks---
    orange_blobs = img.find_blobs([orange_threshold], roi=lines_roi, area_threshold=3000)
    for blob in orange_blobs:
        img.draw_rectangle(blob.rect(),color=(0, 255, 0))
        return True #Returns True if sees an orange blob
    return False #Returns False if it doesn't see an orange blob

#---Detects Blue Line to determine the direction---
def Find_Blue_Line(img):
    blue_threshold = (35, 8, -128, 16, -128, -6) #Color threshold used for blue

    #---Defines a rectangle roi for the floor---
    rect_x = int(0)
    rect_y = int(img_height * 0.3)
    rect_w = int(img_width)
    rect_h = int(img_height)
    lines_roi = (rect_x, rect_y, rect_w, rect_h)
    img.draw_rectangle(lines_roi,color=(255, 0, 0))

    #---Finds similar colored pixel blocks---
    blue_blobs = img.find_blobs([blue_threshold], roi=lines_roi, area_threshold=3000)
    for blob in blue_blobs:
        img.draw_rectangle(blob.rect(),color=(0, 255, 0))
        print(blob.area())
        return True #Returns True if sees a blue blob

    return False #Returns False if it doesn't see a blue blob

#---Detects Red Rectangles (used for object tracking or direction)---
def Find_Red_Rect(img):
    red_threshold = (9, 72, 57, 22, -12, 57) #Color threshold used for red
    blobs_red = img.find_blobs([red_threshold], area_threshold=1000)

    rect = None
    center = None
    error = None
    area = None
    returnSTR = ""

    #---Draws cross at image center---
    img_center_x = img.width() // 2
    img_center_y = img.height() // 2
    img.draw_cross(img_center_x, img_center_y, color=(255, 0, 0))

    #---Finds blobs that match red threshold---
    for a in blobs_red:
        img.draw_rectangle(a.rect())
        x, y, w, h = a.rect()
        img.draw_cross(x + w // 2, y + h // 2)

        #---Check shape (elongation close to rectangle)---
        if a.elongation() < 1.2:
            area = a.area()
            rect = a.rect()
            x, y, w, h = rect
            center = (x + w // 2, y + h // 2)
            error = center[0] - img_center_x
            returnSTR = returnSTR + str([area, error])+"?"

    return returnSTR

#---Detects Green Rectangles (used for object tracking or direction)---
def Find_Green_Rect(img):
    green_threshold = (0, 52, -35, -15, -55, 17) #Color threshold used for green
    blobs_green = img.find_blobs([green_threshold], area_threshold=1000)

    rect = None
    center = None
    returnSTR = ""
    error = 0
    area = 0

    #---Draws cross at image center---
    img_center_x = img.width() // 2
    img_center_y = img.height() // 2
    img.draw_cross(img_center_x, img_center_y, color=(255, 0, 0))

    #---Finds blobs that match green threshold---
    for a in blobs_green:
        img.draw_rectangle(a.rect())
        x, y, w, h = a.rect()
        img.draw_cross(x + w // 2, y + h // 2)

        #---Check shape (elongation close to rectangle)---
        if a.elongation() < 1.2:
            area = a.area()
            rect = a.rect()
            x, y, w, h = rect
            center = (x + w // 2, y + h // 2)
            error = center[0] - img_center_x
            returnSTR = returnSTR + str([area, error])+"?"

    return returnSTR

#---Main Loop---
while True:
    clock.tick()  #Updates the FPS clock
    img = sensor.snapshot()  #Takes a picture from the camera

    #---Reads 1 byte from UART to decide which function to run---
    a = uart1.read(1)

    if a == b'1':
        #---Detects Green Rectangle and sends area + error via UART---
        uart1.write("<" + str(Find_Green_Rect(img)) + "*")
    elif a == b'2':
        #---Detects Red Rectangle and sends area + error via UART---
        uart1.write("<" + str(Find_Red_Rect(img)) + "*")
    elif a == b'3':
        #---Measures brightness in the middle ROI and sends value via UART---
        uart1.write("<" + str(Find_MiddleBrightness(img)) + "*")
    elif a == b'4':
        #---Detects Orange Line and sends True/False via UART---
        uart1.write("<" + str(Find_Orange_Line(img)) + "*")
    elif a == b'5':
        #---Detects Blue Line and sends True/False via UART---
        uart1.write("<" + str(Find_Blue_Line(img)) + "*")

    #---Debugging: print the received UART command and FPS---
    print(a)
    print(clock.fps())
    time.sleep(0.01)  #Small delay for stability
```
---
## Robot Construction Guide 
**Step 1: Assemble the steering system**  
- Print 3D models located in /models
- Mount the GeekServo motor securely onto the chassis using screws or brackets.  
- Connect the steering axle to the servo using a suitable coupling or connector.  
- Ensure the servo mount is firmly fixed so it doesn’t wobble during operation.  
- Install the front steering hubs using a axle to secure them.  
- Make sure the steering arm moves freely and does not collide with the chassis.  

**Step 2: Assemble the powertrain**  
- The motor was mounted securely onto the chassis to ensure stability during operation.
- The GA12-N20 DC motor is placed into the mount and attached firmly (using appropriate fastening components).
- The motor output shaft is connected to an axle and gear mechanism to transmit rotation.
- 
**Step 3: Mount the electronics**
- Attach the Li-ion battery underneath the EVN Alpha.
- Place the EVN Alpha controller onto the chassis and secure it in position using appropriate fastening components.
- Mount the MPU-6500 IMU on the back of EVN Alpha to make it stable during the challenges.
- Install the OpenMV Cam RT1062 onto its holder and slightly tilt the camera downwards for improved line and obstacle detection.

**Step 4: Attach the Wheels**
- Attach the front wheels securely to the steering hubs using appropriate axles.
- Install the rear wheels onto the driven axle that is connected to the motor.
- Add spacers or equivalent components to keep the wheels properly fixed and aligned.

**Step 5: Preparation for operation**
- Ensure the chassis is stable and properly balanced.
- Arrange cables so that they do not interfere with moving parts.

**Step 6: Software setup**
- Connect the controllers and sensors to a computer for programming.
- Upload the control and vision codes located in /src
- Verify that each component (motors, servos, camera, IMU) responds correctly.

## License 

```
GNU General Public License v3.0

Copyright (C) 2007 Free Software Foundation, Inc. <https://fsf.org/>

This program is free software: you can redistribute it and/or modify
it under the terms of the GNU General Public License as published
by the Free Software Foundation, either version 3 of the License, or
(at your option) any later version.

This program is distributed in the hope that it will be useful,
but WITHOUT ANY WARRANTY; without even the implied warranty of
MERCHANTABILITY or FITNESS FOR A PARTICULAR PURPOSE. See the
GNU General Public License for more details.

You should have received a copy of the GNU General Public License
along with this program. If not, see <https://www.gnu.org/licenses/>.

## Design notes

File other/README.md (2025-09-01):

This file contains our robot's parts.

When you click to  ` servo motor `  you can find our servo motor.

When you click to  ` evn `  you can find our motor controller.

When you click to  ` motor `  you can find our metal gearmotor with encoder.

When you click to  ` camera `  you can find the camera we used.

When you click to  ` IMU `  you can find the IMU sensor we used.

When you click to  ` Lego  Differential `  you can find the Lego  differential  we used.

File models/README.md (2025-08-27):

This directrory contains chassis, mechanisms and other designs for the vehicle.

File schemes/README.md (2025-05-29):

This directory contains an electronic schematic diagram of the vehicle's components.

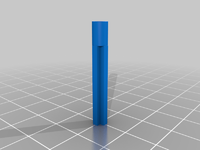
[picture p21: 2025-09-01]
models/AxleAdapter/AxleAdapter.jpeg

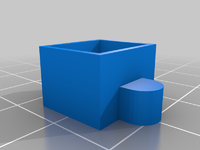
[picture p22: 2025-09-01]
models/MotorMount/MotorMount.jpeg

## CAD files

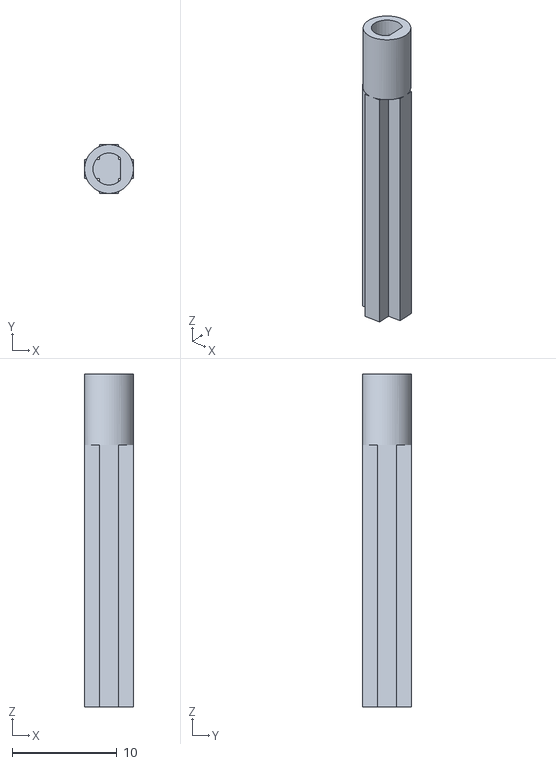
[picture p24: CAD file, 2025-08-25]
models/AxleAdapter/AxleAdapter.stl
4.65 x 4.65 x 31.8

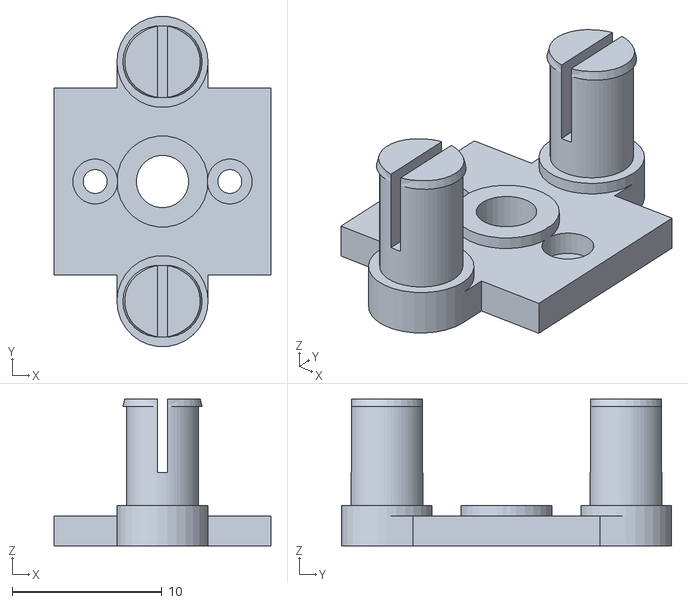
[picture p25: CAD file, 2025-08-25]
models/MotorLegoAdapter/MotorLegoAdapter.stl
14.5 x 22.1 x 9.80

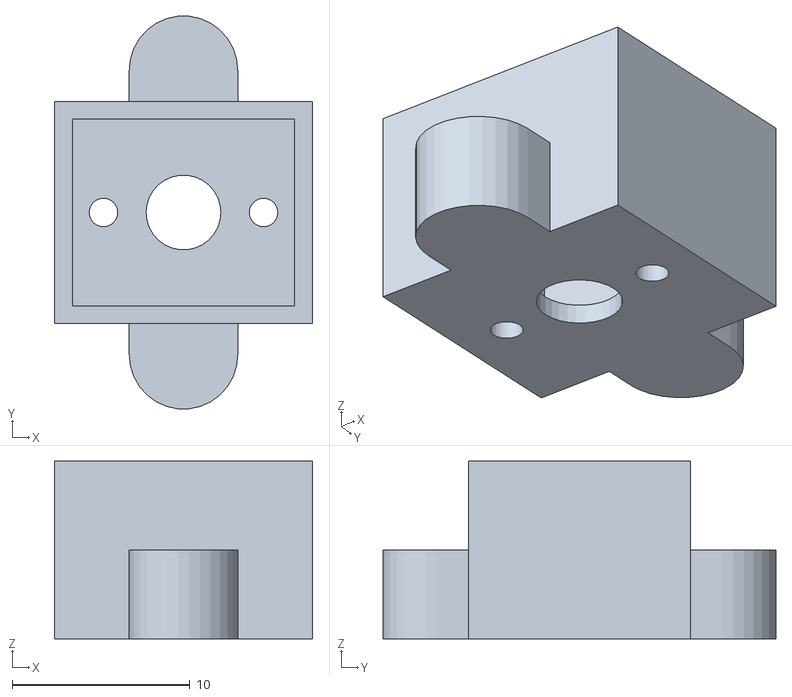
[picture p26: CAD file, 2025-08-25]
models/MotorMount/MotorMount.stl
14.5 x 22.1 x 10.0

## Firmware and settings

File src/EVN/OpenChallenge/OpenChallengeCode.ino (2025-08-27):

#include <EVN.h>
#include <SoftwareSerial.h>
#include <math.h>

//---Constants and configurations---
#define SERVO_DIR_PORT   1
#define IMU_I2C_PORT     1
#define MOTOR_PORT       2
#define PPR_VALUE        2200
#define MAX_RPM          77
#define ACCEL            7700
#define DECEL            7700
#define MOTOR_KP         0.4
#define MOTOR_KD         0.0048

const float SERVO_CENTER = 133;  // Servo neutral position
const int SERVO_RIGHT  = 160;    // Servo right extreme
const int SERVO_LEFT   = 106;    // Servo left extreme

float gyroBias = 0.0f;           // Gyro bias for calibration
unsigned long lastTime = 0;

const byte rxPin = 1;
const byte txPin = 0;
int timeout = 500;

//---Hardware objects---
EVNAlpha board;
EVNServo steeringServo(SERVO_DIR_PORT);
EVNIMUSensor imu(IMU_I2C_PORT);
EVNMotor motor(MOTOR_PORT, CUSTOM_MOTOR, DIRECT, REVERSE);
SoftwareSerial mySerial(rxPin, txPin);


//---Calibrates gyro bias while vehicle is stationary---
void calibrateGyroBias(uint16_t duration_ms = 200) {
  unsigned long t0 = millis();
  uint16_t n = 0;
  double sum = 0.0;

  while (millis() - t0 < duration_ms) {
    float gz = imu.readGyroZ(); // deg/s
    sum += gz;
    n++;
    delay(4); // ~250 Hz sample
  }

  if (n > 0) gyroBias = (float)(sum / n); // average bias
}

//---Calculates cumulative yaw (heading) based on gyro readings---
float yaw = 0.00f;
float updateYaw() {
  unsigned long now = millis();
  float dt = (now - lastTime) / 1000.0f;

  lastTime = now;
  float gz = imu.readGyroZ();   // deg/s
  gz -= gyroBias;                // bias correction
  yaw += gz * dt;                // integrate to get yaw in degrees
  return yaw;
}

//---Performs a gyro-based turn in the specified direction---
void Turn(float Turn_Degree, float kp = 6.66, float turn_start_yaw = 0.0, 
          float min_speed = 40, float max_speed = 400, float Near_Degree = 20.0f,
          int servo_right = 160, int servo_left = 115, int servo_min = 50, int servo_max = 210) {
  delay(1000);                    // Wait before starting
  calibrateGyroBias(200);         // Calibrate gyro before turn

  int turnAngle = (Turn_Degree >= 0.0f) ? servo_right : servo_left;
  steeringServo.write(constrain(turnAngle, servo_min, servo_max));

  float diff = updateYaw() - turn_start_yaw;
  float error = 0;

  //---Loop until target yaw is reached---
  while ((Turn_Degree >= 0.0f) ? (Turn_Degree - diff > 0.1) : (Turn_Degree - diff < 0.1)) {
    diff = updateYaw() - turn_start_yaw;
    error = Turn_Degree - diff;
    int spd = abs(error * kp);

    //---Limit motor speed---
    spd = constrain(spd, min_speed, max_speed);
    motor.runSpeed(spd);
  }

  motor.stop();
  steeringServo.write(constrain(SERVO_CENTER, servo_min, servo_max));
  Serial.println(updateYaw());
}

//---Performs a gyro-based backward turn---
void Turn_Back(float Turn_Degree, float kp = 6.66, float turn_start_yaw = 0.0, 
               float min_speed = 40, float max_speed = 400, float Near_Degree = 20.0f,
               int servo_right = 160, int servo_left = 115, int servo_min = 50, int servo_max = 210) {
  delay(1000);
  calibrateGyroBias(200);

  int turnAngle = (Turn_Degree < 0.0f) ? servo_right : servo_left;
  steeringServo.write(constrain(turnAngle, servo_min, servo_max));

  float diff = updateYaw() - turn_start_yaw;
  float error = 0;

  while ((Turn_Degree >= 0.0f) ? (Turn_Degree - diff > 0.1) : (Turn_Degree - diff < 0.1)) {
    diff = updateYaw() - turn_start_yaw;
    error = Turn_Degree - diff;
    int spd = error * kp;
    spd = constrain(spd, min_speed, max_speed);
    motor.runSpeed(-spd); // reverse
  }

  motor.stop();
  steeringServo.write(constrain(SERVO_CENTER, servo_min, servo_max));
  Serial.println(updateYaw());
}

//---Moves vehicle straight for a specified distance in mm---
void Move(float distance_mm, float speed = 600) {
  steeringServo.write(constrain(SERVO_CENTER, 50, 210)); // center steering
  delay(1000);
  calibrateGyroBias(200);

  long start_pos = motor.getPosition();
  float diameter = 43.2; // wheel diameter in mm
  float distance_degree = 360 * distance_mm / (3.1415 * diameter);

  float start_yaw = updateYaw();
  float error = 0;
  long pos = motor.getPosition() - start_pos;

  while (llabs(pos) < distance_degree) {
    error = updateYaw() - start_yaw;
    steeringServo.write(constrain(SERVO_CENTER - error, 50, 210));
    pos = motor.getPosition() - start_pos;
    motor.runSpeed(speed);
  }

  motor.stop();
}

//---Initializes motor and servo---
void setup1() {
  motor.begin();
  steeringServo.begin();
}

//---Main setup---
void setup() {
  board.begin();
  Serial.begin(9600);
  imu.begin();
  imu.setGyroRange(IMU_GYRO_DPS_1000);

  motor.setPPR(PPR_VALUE);
  motor.setMaxRPM(MAX_RPM);
  motor.setAccel(ACCEL);
  motor.setDecel(DECEL);
  motor.setKp(MOTOR_KP);
  motor.setKd(MOTOR_KD);
  motor.resetPosition();

  steeringServo.write(SERVO_CENTER, 50, 210);
  pinMode(rxPin, INPUT);
  pinMode(txPin, OUTPUT);
  mySerial.begin(9600);

  lastTime = millis();
}

//---Determines vehicle movement direction based on sensor readings---
int find_direction() {
  Serial.println("<");
  String orange = requestOrangeLine();
  String blue = requestBlueLine();
  String bright = requestMiddleBrightness();
  float bright1 = bright.toFloat();
  Serial.println(">");

  if (orange == "True") return 1;
  if (blue == "True") return 2;
  if (bright1 < 9) return 1;
  return 0;
}
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

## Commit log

2025-05-18 Rename Hobby Motor to Lego Axle.stl to HobbyMotor-LegoAxle
2025-05-18 Add model files
    [DShaft-Gear.stl, Motor Holders.stl, Phone Holder.stl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]
2025-05-24 File upload
    Added motor_control and motor_test files to /src/EVN/
2025-05-25 Change encoder to reverse on motor_control_pwm.ino
2025-05-25 Update codes and variables
    Change PPR_VALUE to 1600, MAX_DPS to 480. Constrain throttle from 0 to 100. Both codes work as intended.
2025-05-26 Update motor_control.ino
    Relocate some codes, remove serial debugging transmission, add code to reset servo to middle on setup.
2025-05-26 Create dist_servo_test.ino
    Create code to use distance sensor to control servo angle.
2025-05-27 Create dist_drive.ino
    Commit first version of dist_drive. It follows walls with two dist sensors.
2025-05-28 Create Body.stl
    Commit Chassis 2.1 Body stl file
    [Body.stl]
2025-05-28 Update Body.stl
    Update Body to include steering main part
    [Body.stl]
2025-05-28 Create /other/motor/ folder
2025-05-28 Create /other/servo
2025-05-28 servo motor
2025-05-28 Rename motor tr.png to motor_tr.png
2025-05-29 Upload electronic schematic to schemes/
2025-05-29 Create other/ultrasonic_sensor
2025-05-29 Create arduino_nano
2025-05-29 Create other/arduino_nano
2025-05-29 Update README.md
    Fix Ackermann Steering hyperlink
2025-05-29 Add Battery.png to /other/battery
2025-05-29 add arduino nano datasheet
2025-05-29 Add battery datasheet
2025-05-29 Add motor documentations
2025-05-29 Add servo datasheet
2025-05-29 Add ultrasonic sensor(HCSR04) datasheet
2025-05-29 Update README.md for battery
2025-05-29 Add chassis images
2025-05-29 Reorganize models
    [Body.stl, D6 gear v3.stl, Motor Holders.stl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]
2025-05-29 Schematic pdf -> jpg
2025-05-29 Update README.md
    Add motor specs, change/fix content table
2025-08-25 Create servo

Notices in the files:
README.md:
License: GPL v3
